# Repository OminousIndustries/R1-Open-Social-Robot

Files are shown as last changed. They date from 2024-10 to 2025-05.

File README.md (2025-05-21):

# R1 DIY Robot Kit

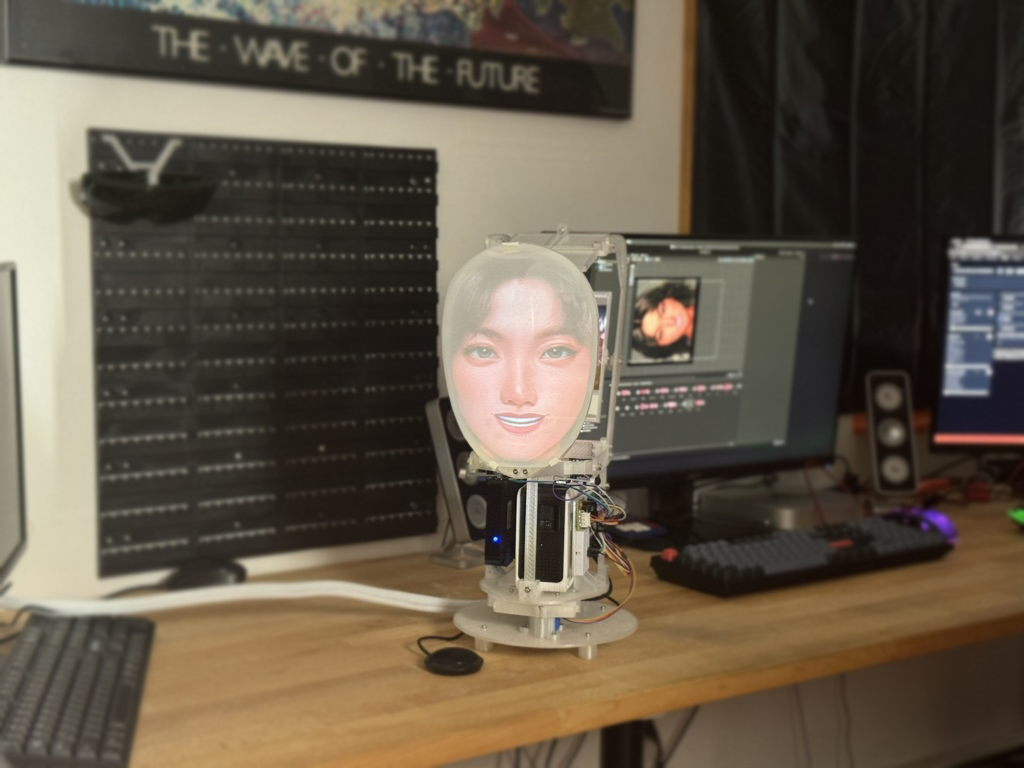
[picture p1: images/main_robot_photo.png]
Assembled R1 DIY Robot

*Assembled R1 DIY Robot with face projection, ready for interaction.*

Welcome to the **R1 DIY Kit**! These files contain every step needed to manufacture and build your very own R1 robot. This DIY kit is based on the original R1 design, with the same internal design and hardware. 

While most instructions are provided in video format, important details can also be found in the accompanying README PDFs throughout the repository. Please read the provided documentation carefully to ensure successful assembly and setup.

## Table of Contents

1. [Gather Required Parts](#gather-required-parts)
2. [3D Printing Files](#3d-printing-files)
3. [Build Instructions](#build-instructions)
4. [Software Setup](#software-setup)
   - [Pre-Setup](#pre-setup)
   - [Robot Computer Setup](#robot-computer-setup)
   - [Installing Unity](#installing-unity)
   - [Starter Mode for Mac](#starter-mode-for-mac)
   - [Starter Mode for Windows](#starter-mode-for-windows)
   - [Face Adjustment](#face-adjustment)
   - [Pausing the Robot](#pausing-the-robot)
   - [Custom Faces](#custom-faces)
   - [Arduino Setup](#arduino-setup)
   - [Advanced Mode](#advanced-mode)
5. [Unity Project Files](#unity-project-files)
6. [Connecting to a Local LLM](#connecting-to-a-local-llm)
7. [Connecting to Google Gemini API](#connecting-to-google-gemini-api)

---

## 1. Gather Required Parts

Before you begin building, print the files and gather all the necessary parts. Here is the bill of materials with links to the components you will need to purchase:

- [Parts List README (PDF)](./pre-setup/R1_Parts_List_README.pdf)

---

## 2. 3D Printing Files

The robot's frame is 3D printed. All the necessary STL files and instructions for printing are included in the following folder. Please refer to the "Printing Guide PDF" for important details about printing the pieces:

- [STL Files for 3D Printing](./build-instructions/Printing_Files)
- [Printing Guide (PDF)](./build-instructions/R1_Printing_Readme.pdf)

---

## 3. Build Instructions

Once you have printed all the parts, it's time to assemble the robot. Follow the video link and refer to the provided assembly guide for detailed instructions:

- [Assembly Instructions PDF](./build-instructions/Instruction_README.pdf)
- [Build Instruction Video](https://youtu.be/2tXyRC_KmT0)

---

## 4. Software Setup

After building the robot, the next step is setting up the software. Most of the instructions are in video format, and the following index outlines the sequence to follow for setting everything up.

### Pre-Setup

Start by setting up the required API keys. You will need both an OpenAI API Key and an Azure Key.

- [Azure Key Setup Video](https://youtu.be/wxKWgDN9a2c)
- [OpenAI Key Setup Video](https://youtu.be/aMjvTZvdCsI)

---

### Robot Computer Setup

Next, set up the robot's computer to run the required software. Follow the instructions in the video below:

- [Computer Setup Video](https://youtu.be/bzLXkPkEXfA)

---

### Installing Unity

You will need to install a specific version of Unity to configure the robot. This guide covers installation for both Mac and Windows users:

- [Unity Installation Video (Cross-platform)](https://youtu.be/6DMLwrmqWGs)

---

### Starter Mode for Mac

Mac users should follow the instructions in the video below to set up Starter Mode for the robot:

- [Starter Mode Mac Video](https://youtu.be/YG3O_CxVHSQ)

---

### Starter Mode for Windows

Alternatively, Windows users can follow this video for setting up Starter Mode:

- [Starter Mode Windows Video](https://youtu.be/5EzZFH6TbZU)

---

### Face Adjustment

Once the software is set up, you may want to adjust the robot's projected face. This video provides a comprehensive overview of how to make these adjustments. Make sure to read the accompanying PDF for important projector notes:

- [Face Adjustment Video](https://youtu.be/Ks0d70vO0KM)
- [Projector README (PDF)](./face-adjustment/Projector_README.pdf)

---

### Pausing the Robot

To learn how to pause and resume the robot while it is running, refer to the following video:

- [Pausing the Robot Video](https://youtu.be/hnXKXJgQXd8)

---

### Custom Faces

You can add custom faces to the robot. Instructions are available for both Mac and Windows users. Additionally, the face template images referenced in the instructional videos are included:

- [Custom Faces for Mac Video](https://youtu.be/4W-XHF8ed94)
- [Custom Faces for Windows Video](https://youtu.be/J4PsrUzNvfo)
- [Face Template Images](./custom-faces/Face_Template_Images)

---

### Arduino Setup

The Arduino controls the head movement of the robot. Use the following instructions to set it up, and make sure to use the provided circuit diagram and Arduino sketches:

- [Arduino Setup Video](https://youtu.be/LZN1rNx5XJ8)
- [Circuit Diagram (PNG)](./arduino-setup/Circuit_Diagram.png)
- [Simple Sketch (Arduino Script)](./arduino-setup/Simple_Sketch.ino)
- [Advanced Sketch (Arduino Script)](./arduino-setup/Advanced_Sketch.ino)

---

### Advanced Mode

For more advanced functionality, such as modifying the robot's mouth sprites and other detailed features, follow the instructions in the advanced video below:

- [Advanced Mode Video](https://youtu.be/tfWZQt3Dw8M)

---

## 5. Unity Project Files

The R1 robot has two versions of the Unity project, each with different mouth sprites. The **r1-starter-mode-f** contains female mouth sprites, while **r1-starter-mode-m** contains male mouth sprites. You can choose which one to use based on your preference:

- [Starter Mode Female Project (Unity)](./r1-starter-mode-f)
- [Starter Mode Male Project (Unity)](./r1-starter-mode-m)

---

## 6. Connecting to a Local LLM

The R1 robot can be powered by a locally hosted language model, providing real-time conversational abilities. These instructions cover setting up the robot to work with [Oobabooga's text-gen-webui](https://github.com/oobabooga/text-generation-webui) as the backend for a Local LLM.

This setup allows the robot to connect to and be powered by a locally hosted AI model of your choosing.

### Step-by-Step Instructions

1. **Setting Up the Unity Project**:
   - Navigate to the `LocalLLM` folder, which contains two scripts: `RoboLogic.cs` and `RoboListen.cs`.
   - In your Unity project, open the existing `RoboLogic.cs` and `RoboListen.cs` scripts.
   - Replace the contents of these scripts with the versions from the `LocalLLM` folder. This will configure the robot to communicate with the local LLM setup.

2. **Starting the Web UI with the Correct Flags**:
   - Launch the web UI with the `--listen` flag to allow external connections.
   - In the web UI, go to the **Session** tab and select the **OpenAI** extension. Click **Apply** and restart the session.

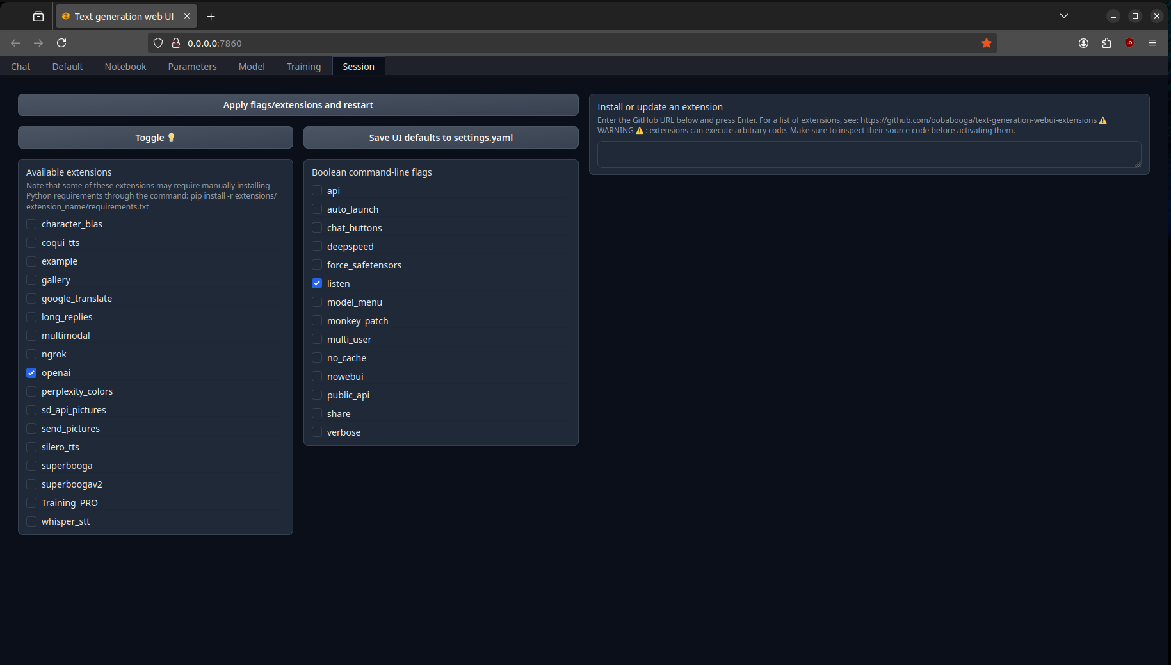
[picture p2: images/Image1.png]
Session Tab - OpenAI Extension
   

3. **Load Your Chosen Model**:
   - Load the AI model you wish to use as you normally would within the web UI.
   - Ensure that the machine running the web UI is configured to allow communication on **port 5000**, which is required for the robot to connect.

   For more detailed information on setting up the OpenAI API within the text-gen-webui, refer to [this guide](https://github.com/oobabooga/text-generation-webui/wiki/12-%E2%80%90-OpenAI-API).

4. **Configuring Unity for Local LLM Connection**:
   - In Unity’s **Inspector** pane, enter the name of the character you wish to communicate with in the web UI, as well as the endpoint URL for the web UI machine.

   Local LLM Connection Settings in Unity Inspector

   - To find the character name in the web UI, go to **Parameters > Chat > Character**.

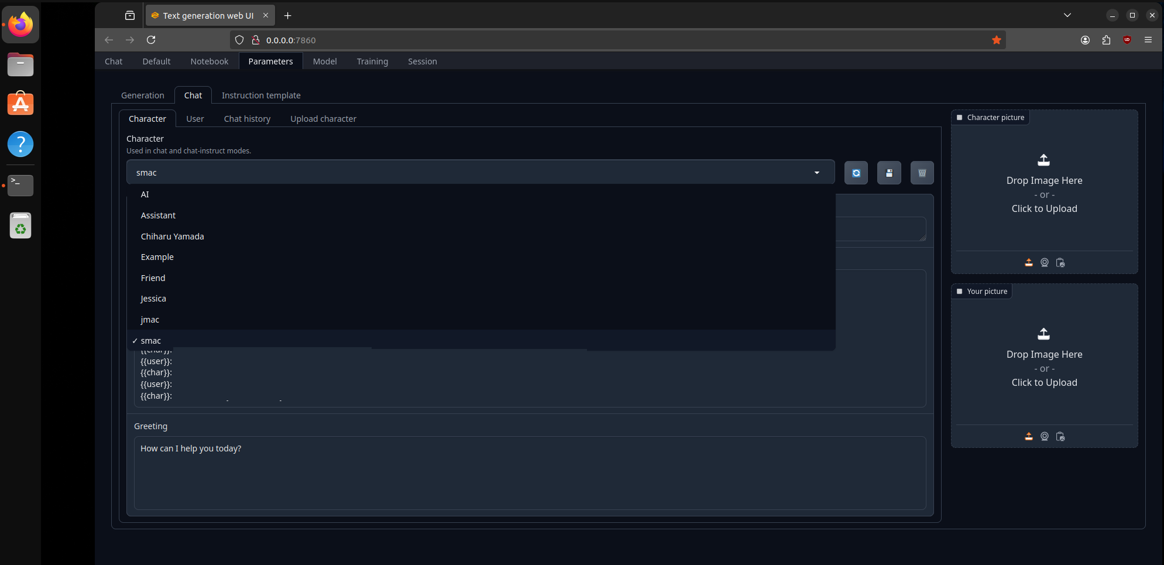
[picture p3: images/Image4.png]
Character Selection in Web UI
   

5. **Testing the Connection**:
   - If everything is configured correctly, you should see the LLM processing requests from the robot in the terminal where the web UI is running.

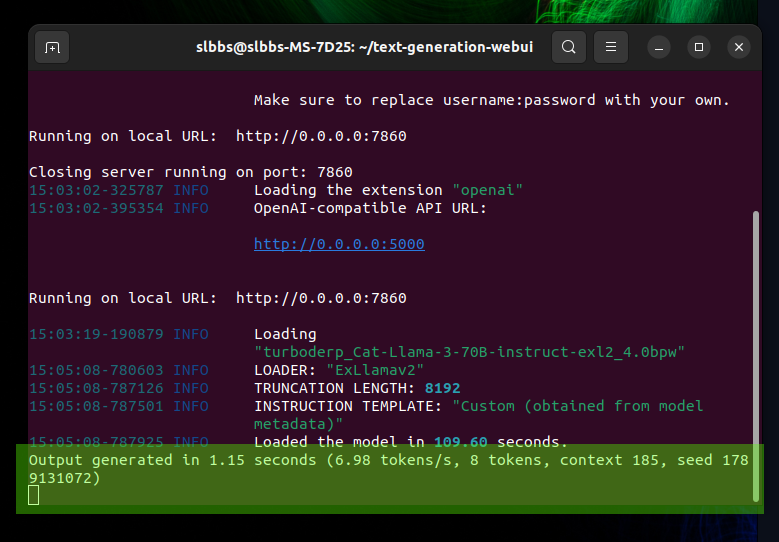
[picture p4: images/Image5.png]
Terminal Output on LLM Machine
   

---

## 7. Connecting to Google Gemini API

The R1 robot can also be configured to use Google's Gemini API for its conversational abilities, as an alternative to a local LLM or other services. This setup uses the `RoboLogic.cs` script which has been adapted for the Gemini API.

### Prerequisites:

*   **Google Cloud Project:** You need a Google Cloud Project set up.
*   **Gemini API Enabled:** Ensure the "Generative Language API" (or "Vertex AI API" if accessing Gemini through Vertex) is enabled for your project.
*   **API Key:** You must have an API key associated with your project that is authorized to use the Gemini API.

### Step-by-Step Instructions:

1.  **Obtain your Google API Key:**
    *   Go to the [Google Cloud Console](https://console.cloud.google.com/).
    *   Navigate to your project.
    *   Go to "APIs & Services" > "Credentials".
    *   Create a new API key if you don't have one, or use an existing key. Ensure it's properly restricted for security, but allows access to the Generative Language API.
    *   **Important:** Keep this API key secure. Do not share it publicly or commit it directly into version control if you are managing your project on a public repository.

2.  **Configure Unity Project:**
    *   Open your R1 Unity project (e.g., `r1-starter-mode-f` or `r1-starter-mode-m`).
    *   Locate the GameObject that has the `RoboLogic.cs` script attached to it (this is typically the main robot controller object).
    *   In the Unity Inspector window for this GameObject, you will find the following fields under the "Robo Logic" component:
        *   **Gemini Api Key:** Paste your Google API Key here.
        *   **Gemini Model Name:** Enter the specific Gemini model you wish to use (e.g., `gemini-1.5-flash-latest`, `gemini-pro`, `gemini-1.0-pro`). The default is often `gemini-1.5-flash-latest`. You can find available model names in the [Google AI documentation](https://ai.google.dev/models/gemini).

    Gemini API Connection Settings in Unity Inspector 
    *(Note: You will need to add an illustrative image named `Gemini_Inspector_Setup.png` to the `images/` directory later if you want this image to show. For now, the markdown link is a placeholder.)*

3.  **Ensure Correct Scripts:**
    *   Make sure the `LocalLLM/RoboLogic.cs` script in your Unity project is the version that has been modified for Gemini API access. If you downloaded the project after these changes, it should be correct. If you are modifying an older version, ensure you've updated the script.

4.  **Testing the Connection:**
    *   Run the Unity scene.
    *   When the robot attempts to get a response (e.g., after speech-to-text processing via `RoboListen`), it will now call the Google Gemini API.
    *   Check the Unity Console for any log messages from `RoboLogic.cs`. Successful calls will log the received response, while errors will detail issues with the API key, model name, endpoint, or network connectivity.

### Important Considerations:

*   **API Costs:** Using the Google Gemini API may incur costs based on your usage. Familiarize yourself with the [Gemini API pricing](https://ai.google.dev/pricing).
*   **Rate Limits:** Be aware of any rate limits imposed by the API to avoid service interruptions.
*   **Security:** Handle your API key with care. For more advanced or production scenarios, consider more secure ways to manage API keys rather than pasting them directly into the Inspector, such as using environment variables or a secure configuration service (though this is beyond the scope of the current basic setup).

---

If you have any questions, feel free to reach out to me. Enjoy building your R1 robot, and remember to follow all safety guidelines when working with tools and equipment!

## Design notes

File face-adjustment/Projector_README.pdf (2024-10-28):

## R1 ROBOT PROJECTOR README

Projector Setup:
The R1 has been designed around the Yoton Y3 projector, as it provides a large amount of light and a high quality image. The projector includes an internal speaker which outputs a suitable volume level for a home setting. If you would like, a 3.5mm aux cable plugged into the bottom headphone jack on the projector will allow you to plug into an external speaker system to output a louder volume.
The Yoton Y3 Projector has a keystone and focus knob which must be adjusted until the screen is clearly displayed on the Face Sheet. The Projector’s instruction manual will guide you on how to do this.

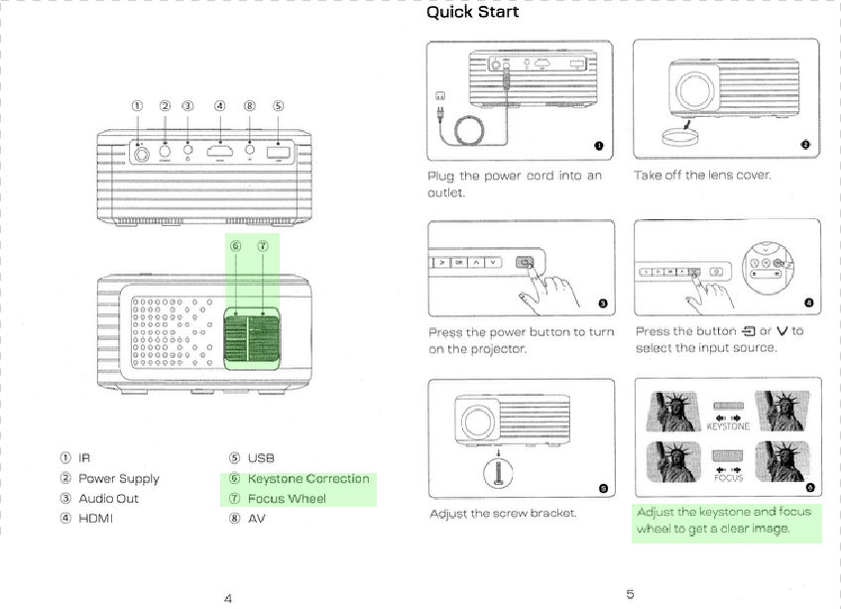
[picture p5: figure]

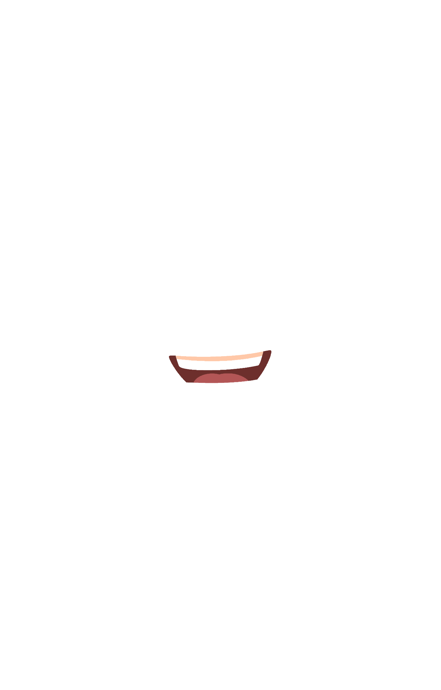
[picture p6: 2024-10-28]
r1-starter-mode-m/Assets/1Robot_Starter_Mode/Sprites/Mouth_Sprites/a,-e,-i.png

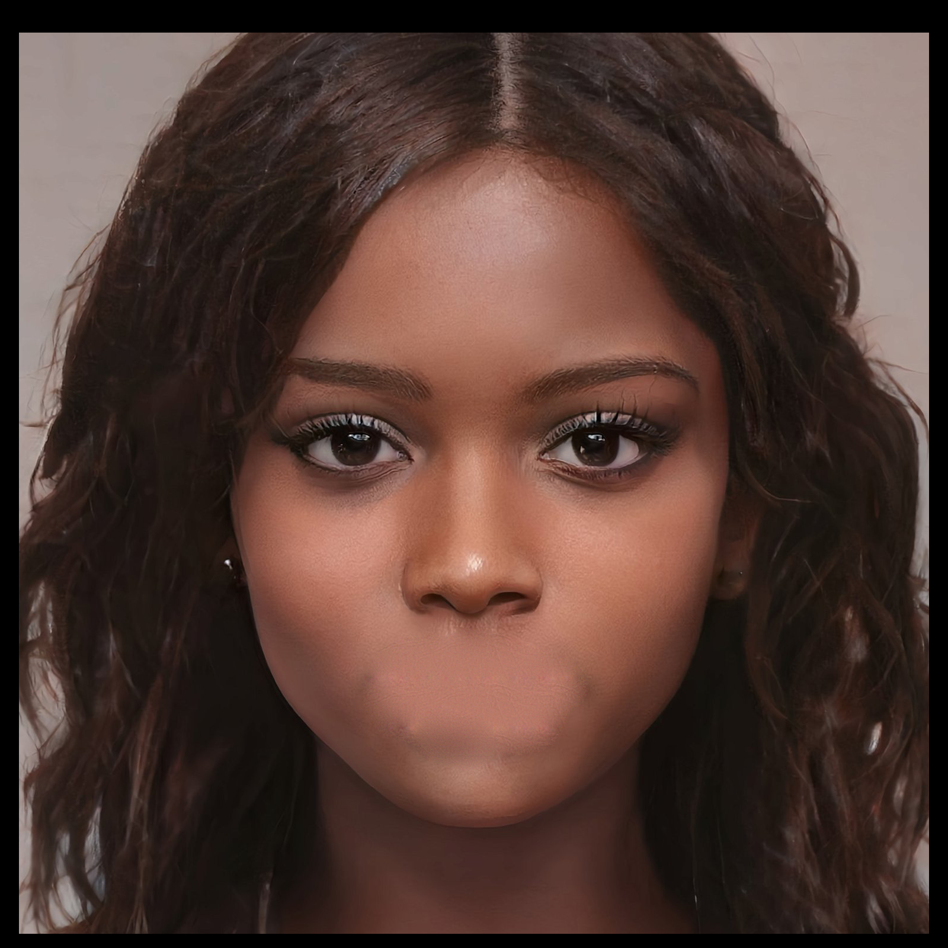
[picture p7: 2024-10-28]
r1-starter-mode-f/Assets/1Robot_Starter_Mode/Sprites/Faces/Face2.png

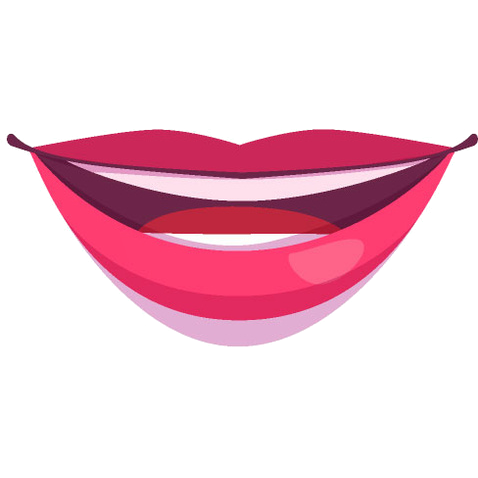
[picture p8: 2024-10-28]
r1-starter-mode-f/Assets/1Robot_Starter_Mode/Sprites/Mouth_Sprites/aei.png

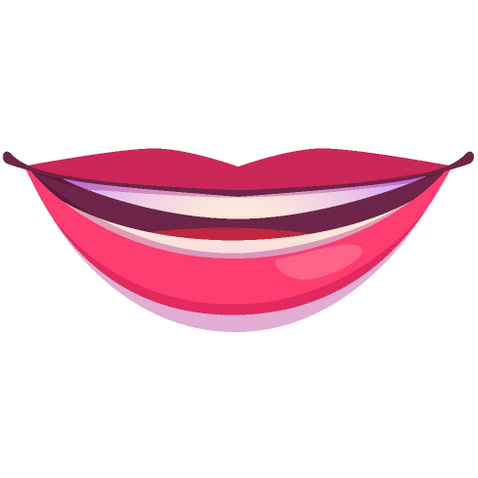
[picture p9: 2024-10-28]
r1-starter-mode-f/Assets/1Robot_Starter_Mode/Sprites/Mouth_Sprites/cdgh.png

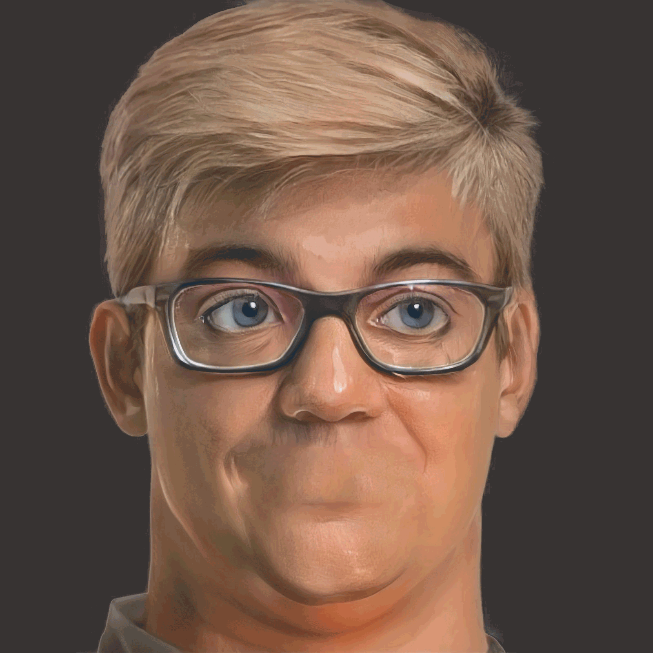
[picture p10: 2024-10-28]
r1-starter-mode-m/Assets/1Robot_Starter_Mode/Sprites/Faces/man3x.png

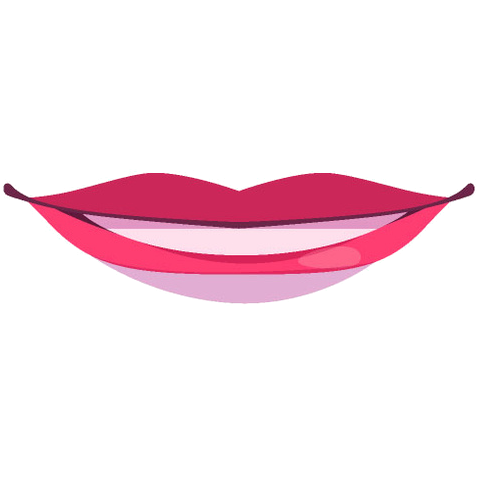
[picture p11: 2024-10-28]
r1-starter-mode-f/Assets/1Robot_Starter_Mode/Sprites/Mouth_Sprites/fv.png

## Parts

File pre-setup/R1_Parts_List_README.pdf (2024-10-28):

R1BOM.md | 2024-10-28

1 / 2

# R1 Robot Bill Of Materials

## Electronic Components

Yoton Y3 Mini Projector: Link (https://amzn.to/40mGHHc)
The Robot is designed to use this specific projector. Other Mini Projectors may work, but this cannot be guaranteed.

T95 Super Android TV Box: Link (https://amzn.to/48n9oWm)
This is the Robotʼs computer. Alternative Android TV boxes, such as the T95 Mini, may work, but this cannot be guaranteed.

Genuine Arduino Uno R3: Link (https://amzn.to/40lqDoL)

Elegoo Arduino Uno R3: Link (https://amzn.to/4e5dfs8)
Generic Uno R3 models, like the Elegoo model, can also work if you are familiar with Arduino.

28BYJ-48 Stepper Motor & ULN2003 Driver Board: Link (https://amzn.to/3NOcMzP)
The robot only needs one of each, but they are sometimes cheaper and more readily available to purchase as a package.

Mini Breadboard 170 Point: Link (https://amzn.to/3NH0glL)
This is the recommended size breadboard to use with the R1.

LM393 3-Pin Arduino Sound Level Sensor: Link (https://amzn.to/48kJJO5)
(Two Sensors Required) It is advised to use the 3-Pin LM393-based sound level sensors. If you are familiar with Arduino, you may also adapt the 4-Pin sensors.

Arduino Jumper Wires: Link (https://amzn.to/4fj8cWf)
The Robot needs 12 M-F and 2 M-M 20CM Jumper wires.

Generic USB Microphone: Link (https://amzn.to/4ebU9Ru)
Any universal microphone should work with the Robotʼs computer, but this cannot be guaranteed.

1 foot HDMI Cable: Link (https://amzn.to/3C0lubH)
A 1-foot HDMI cable is easy to neatly tuck behind the robot.

Right-Angle Male to Female HDMI Adaptor: Link (https://amzn.to/4fl01Zp)
Either the 90 or 270-degree adaptors will work as the cable will reach on either side.

USB A to USB A Cable: Link (https://amzn.to/3YG3EUr)
This is to transfer the software from your computer to the Robotʼs computer. If you plan to use ADB to transfer files instead, this cable is not necessary.

## Hardware

3mm thick 6”x4” Acrylic Mirror: Link (https://amzn.to/3Ah2g12)
(Two Mirrors Required) For the DIY Kit R1, both mirrors are the same size, as opposed to the larger rear mirror displayed in the instructions. Any 3mm thick 6” by 4” mirror should work. Some multi-

R1BOM.md | 2024-10-28

2 / 2

pack mirrors on Amazon may appear to be the right size, but are really 3.9" by 5.9" and will not fit in the robot. Using these would require modifying the robot's mirror holders.

10 mil Mylar Sheet 12 x 12 inch Milky Translucent PET: Link (https://amzn.to/3C0lFDT)
This material allows the face to be projected on the robot. Other materials may work, but 10mil milky translucent PET has worked well in prototyping.

Hex Socket Head M4 Screw and Nut Set: Link (https://amzn.to/4fizBHM)
Most of the Robotʼs assembly requires M4 sized hardware.

Hex Socket Head M2, M3, M4 Screw and Nut Set: Link (https://amzn.to/4hpga1E)
Some M2 and M3 hardware is also necessary, and this also supplies extra M4 hardware if needed.

4mm Nylon Spacer for Sound Level Sensor: Link (https://amzn.to/4hpfZ6u)
This is not required as the sound level sensors can mount directly to the front crossmember, but these spacers allow the sensors to sit at a better angle.

Two 1kg Rolls of 3D Printer Filament of Your Choosing: Link (https://amzn.to/4hpikyk)
There is no specific recommendation for filament type. Choose any color and material you prefer; two 1kg rolls should be plenty. Esun PLA Plus has been reliable in prototyping.

As an affiliate, I may earn a commission from qualifying purchases at no extra cost to you.

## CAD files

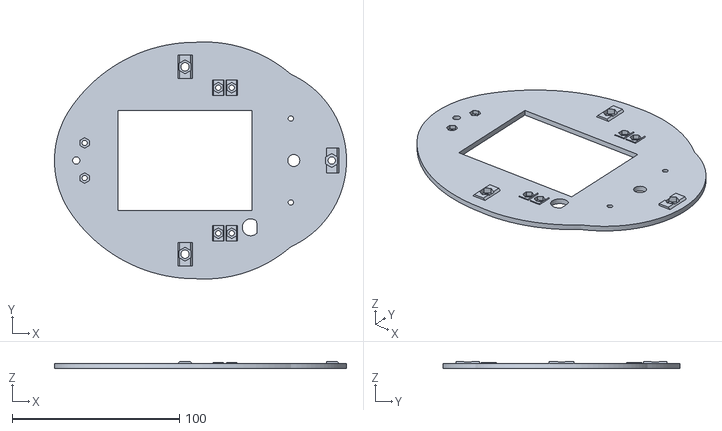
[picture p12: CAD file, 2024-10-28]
build-instructions/Printing_Files/Base/Robo_Base.stl
174.5 x 141.7 x 4.15

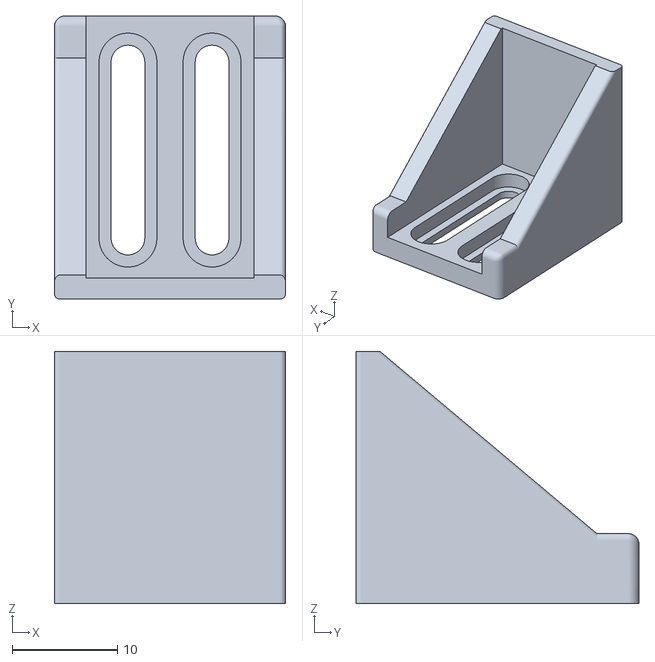
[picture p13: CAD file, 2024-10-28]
build-instructions/Printing_Files/Clamps/Side_Projector_Clamp.stl
22.0 x 26.9 x 24.0

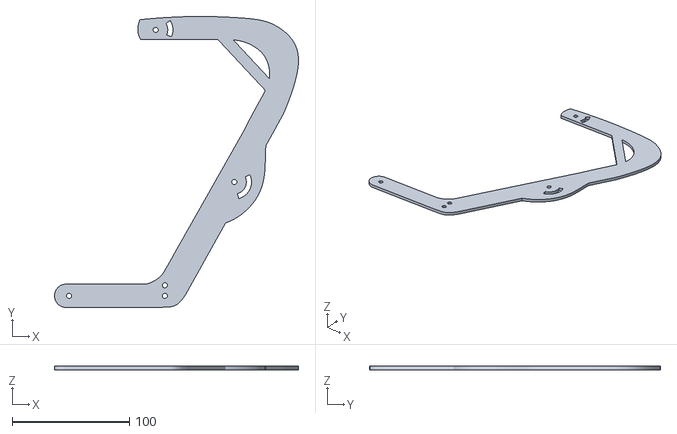
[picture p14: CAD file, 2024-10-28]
build-instructions/Printing_Files/HeadFrame/Head_Frame.stl
208.4 x 248.5 x 3.00

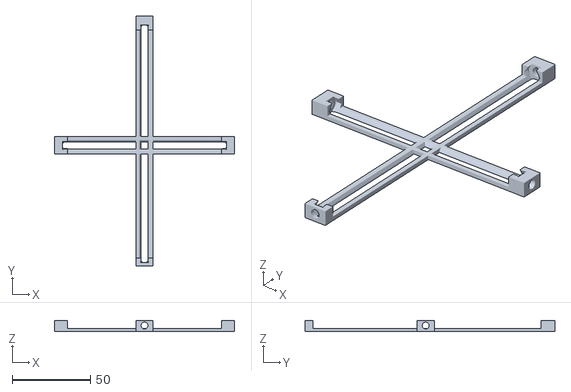
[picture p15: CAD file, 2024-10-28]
build-instructions/Printing_Files/Mirrors/Top_Mirror_Bridge.stl
115.0 x 159.4 x 6.96

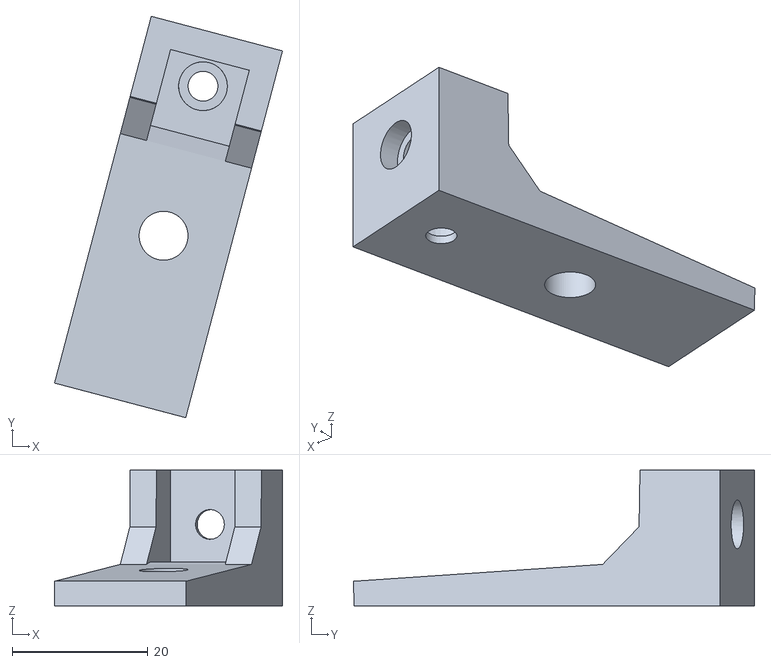
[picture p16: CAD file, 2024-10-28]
build-instructions/Printing_Files/Mounts/Front_Post_Mount.stl
33.6 x 59.1 x 20.0

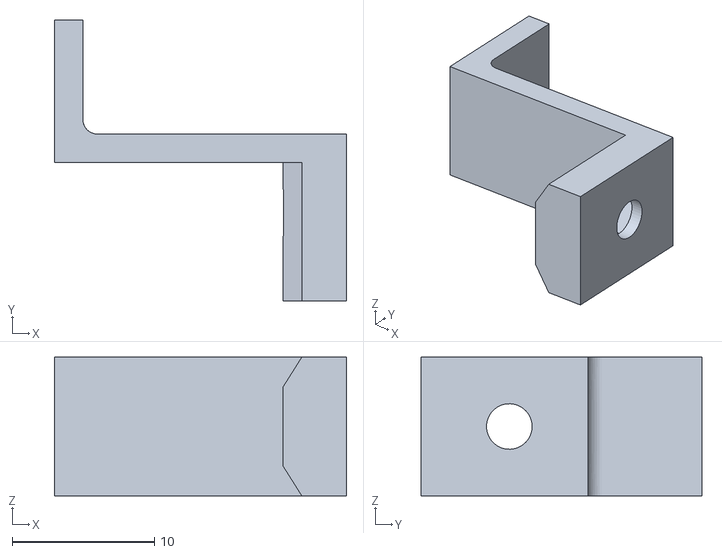
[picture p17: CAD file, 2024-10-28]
build-instructions/Printing_Files/Posts/Top_Computer_Bracket.stl
20.5 x 19.7 x 9.75

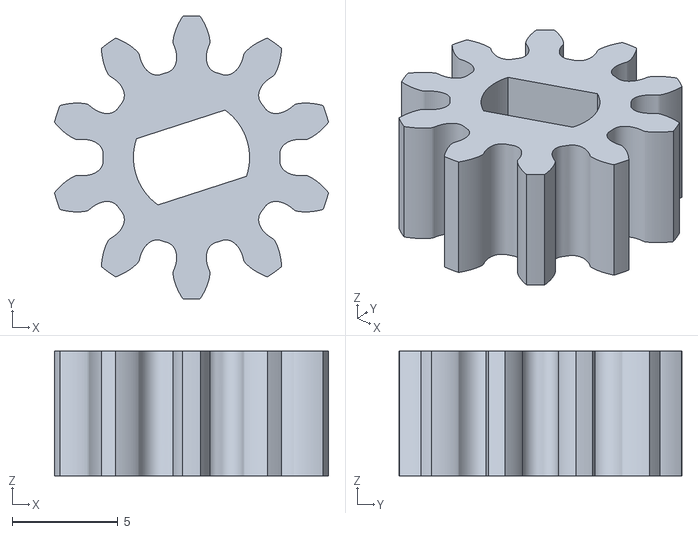
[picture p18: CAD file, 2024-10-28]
build-instructions/Printing_Files/Base/Gear_Updated.stl
13.0 x 13.4 x 5.90

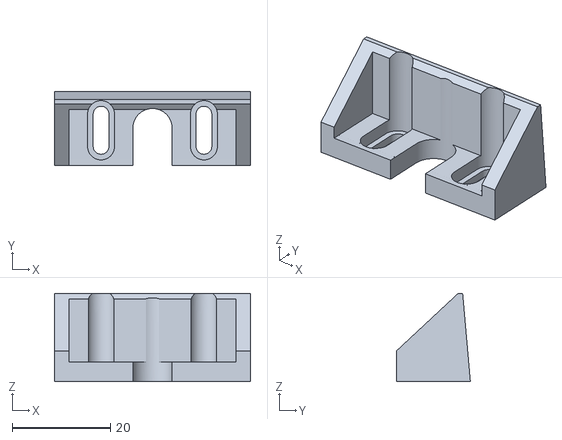
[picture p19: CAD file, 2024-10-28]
build-instructions/Printing_Files/Clamps/Rear_Projector_Clamp.stl
40.0 x 15.1 x 18.0

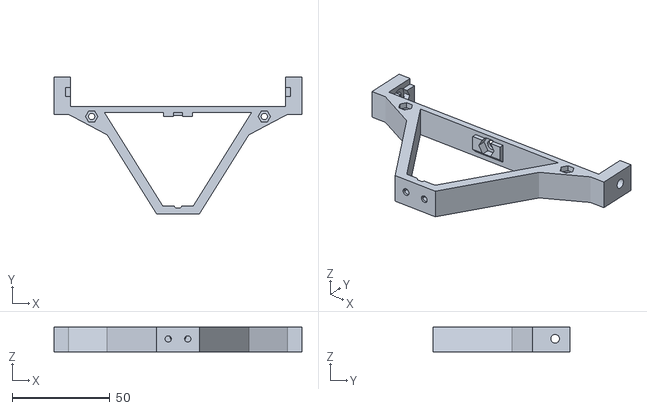
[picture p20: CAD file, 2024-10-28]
build-instructions/Printing_Files/HeadFrame/Front_Crossmember.stl
127.0 x 70.0 x 12.8

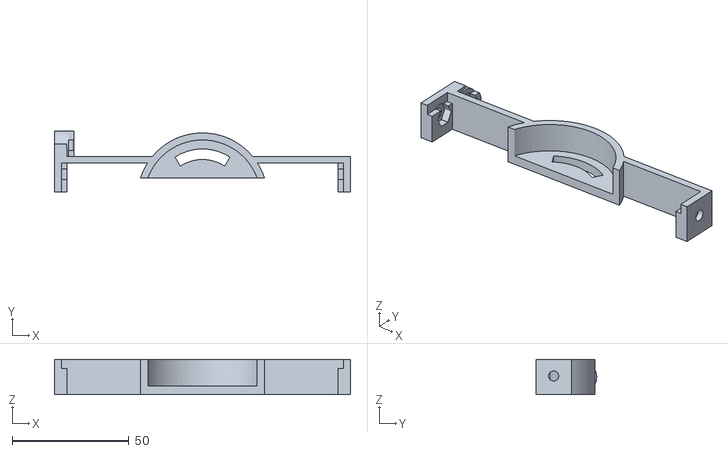
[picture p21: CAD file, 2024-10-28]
build-instructions/Printing_Files/Mirrors/Rear_Mirror_Support.stl
127.0 x 26.0 x 15.1

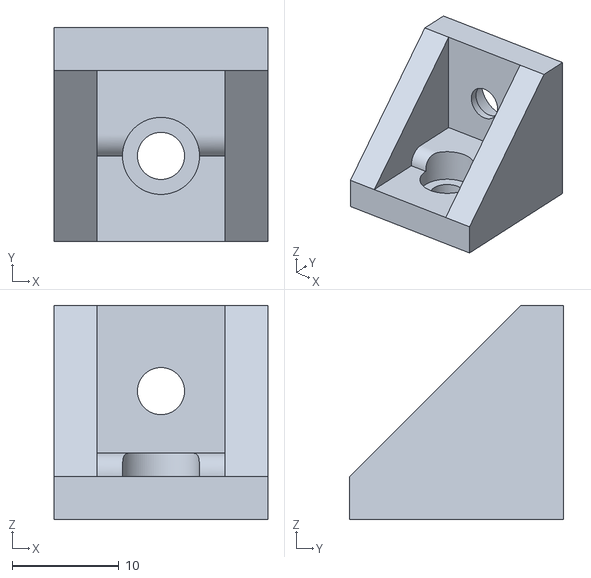
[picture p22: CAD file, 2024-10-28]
build-instructions/Printing_Files/Mounts/Side_Post_Mount.stl
20.0 x 20.0 x 20.0

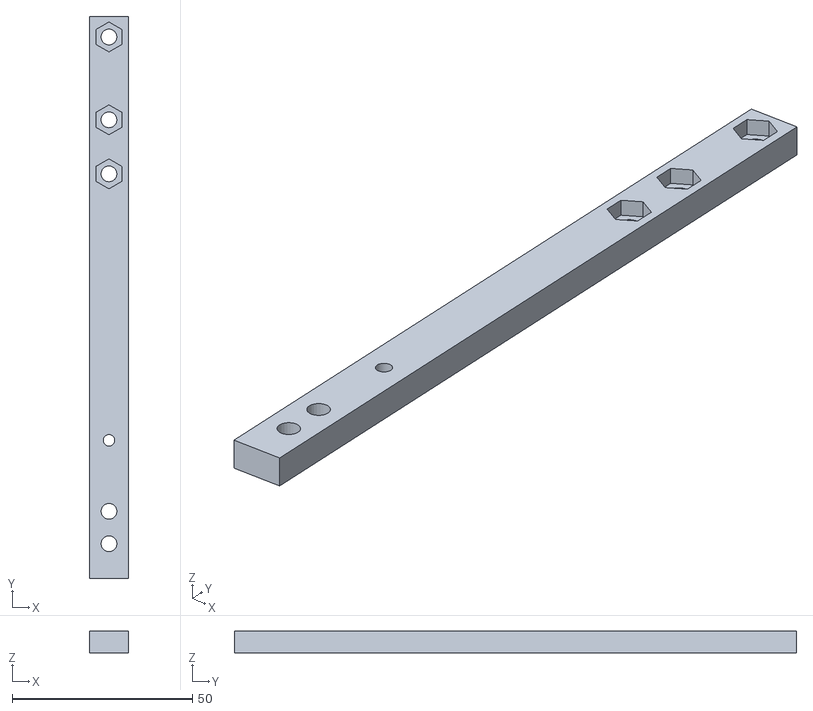
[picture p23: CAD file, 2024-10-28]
build-instructions/Printing_Files/Posts/Computer_Side_Post.stl
10.8 x 156.0 x 6.00

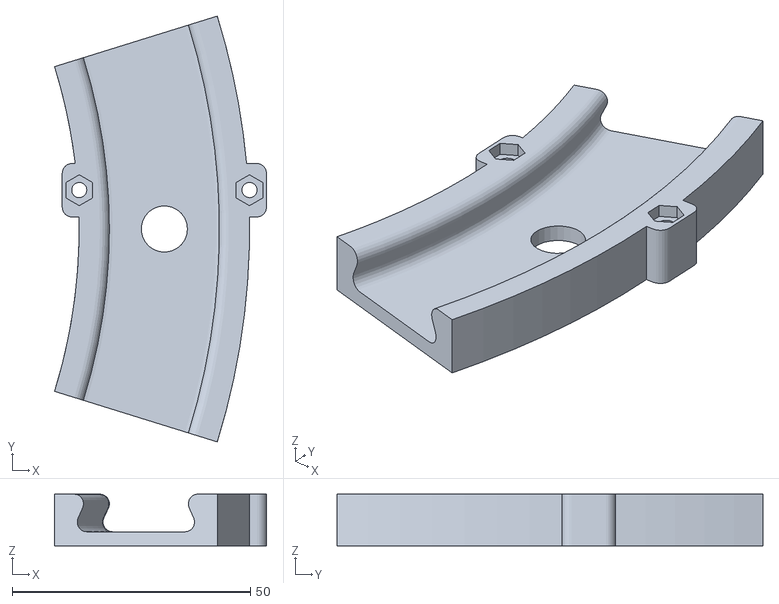
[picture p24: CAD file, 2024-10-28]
build-instructions/Printing_Files/Base/Rail_Slider.stl
44.5 x 89.3 x 10.9

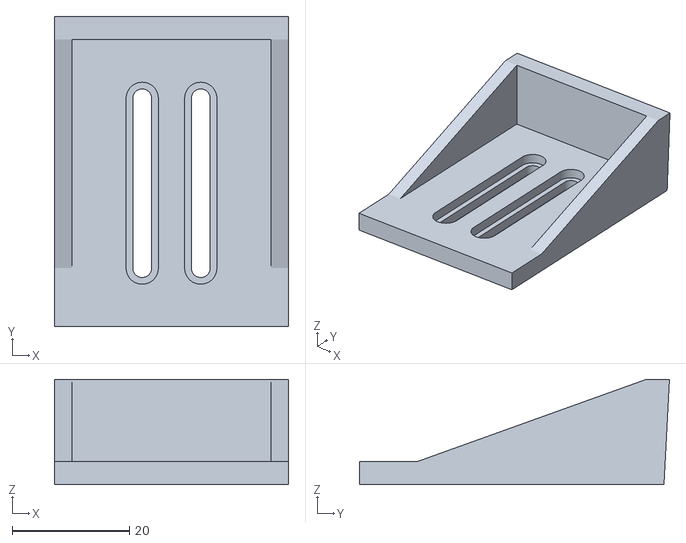
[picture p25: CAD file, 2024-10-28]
build-instructions/Printing_Files/Clamps/Top_Projector_Clamp.stl
40.0 x 52.9 x 18.0

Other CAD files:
build-instructions/Printing_Files/HeadFrame/Face_Bezel.stl
build-instructions/Printing_Files/Mirrors/Rear_Mirror_Bridge.stl
build-instructions/Printing_Files/Posts/Arduino_Mount.stl
build-instructions/Printing_Files/Base/Motor_Mount.stl
build-instructions/Printing_Files/Base/Base_Plate.stl
build-instructions/Printing_Files/Base/Gear_Rail.stl
build-instructions/Printing_Files/Base/Rear_Base_Mount.stl
build-instructions/Printing_Files/Base/Robo_Foot.stl
build-instructions/Printing_Files/HeadFrame/Rear_Crossmember.stl
build-instructions/Printing_Files/Mirrors/Rear_Mirror_Bezel.stl
build-instructions/Printing_Files/Mirrors/Top_Mirror_Bezel.stl
build-instructions/Printing_Files/Posts/Arduino_Side_Post.stl
build-instructions/Printing_Files/Posts/Computer_Mount.stl
build-instructions/Printing_Files/Posts/Front_Post.stl

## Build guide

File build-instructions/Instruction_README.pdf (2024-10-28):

## R1 ROBOT INSTRUCTION README

Because this kit is designed to be easily assembled at home, the two piece external shell from the old R1 has been replaced with a simpler face sheet that can be easily built. Due to this change, some of the instructions in the R1 build video will be slightly different to what you will be building here. Highlighted below are the changes made to be aware of when watching the instruction build video:
In Step 22, The M4 Lock Nut may have a different colored gasket than the blue that is mentioned in the video.
In Step 33, The Computer Side Post no longer requires the two parallel M4 nuts that go in the protruded areas.

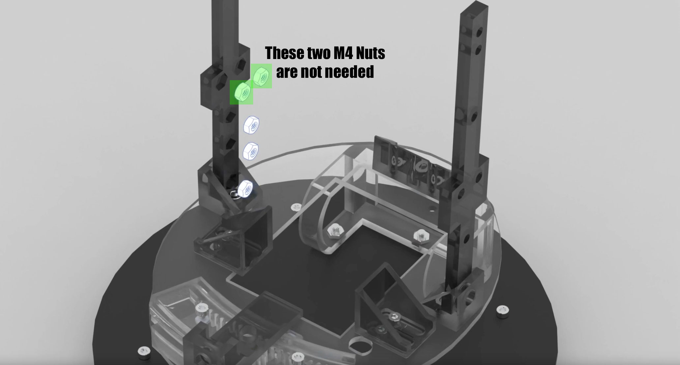
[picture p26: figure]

In Step 34, the Arduino Side Post shows a post with a side protrusion for two M4 nuts. The updated post does not have these protrusions and does not need the nuts placed there. (See Image Below)

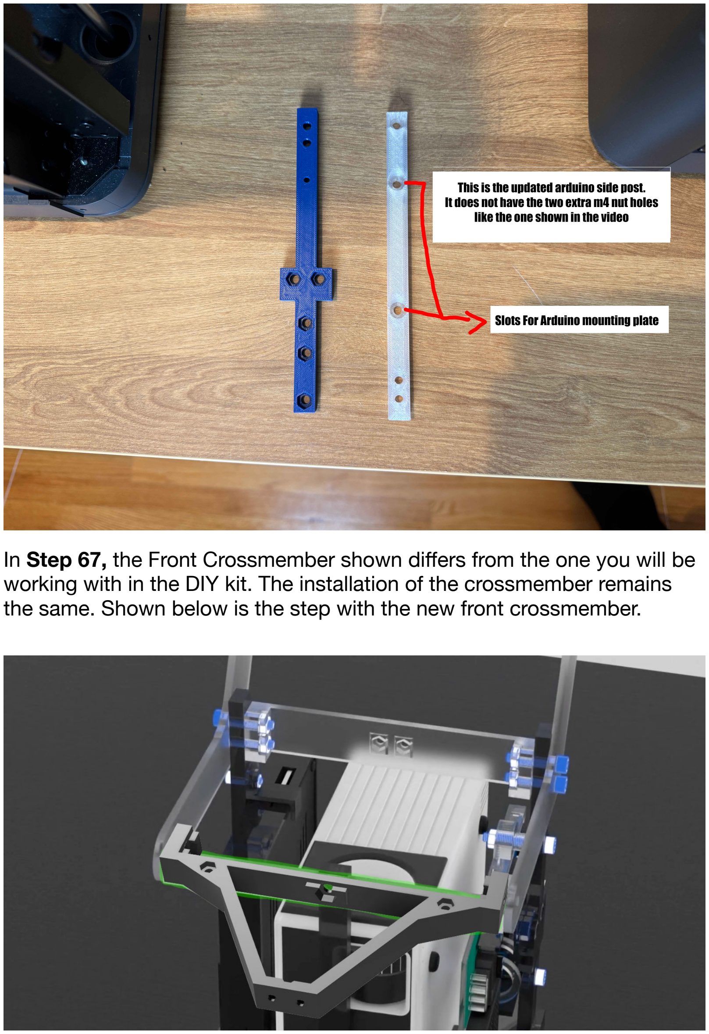
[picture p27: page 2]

In Step 67, the Front Crossmember shown differs from the one you will be working with in the DIY kit. The installation of the crossmember remains the same. Shown below is the step with the new front crossmember.

The two mirrors used in the Robot are the same size in the DIY kit. Due to this, the mention of the larger rear mirror beginning just before Step 82, can be ignored as both mirrors are the same size.
The Build Instruction video skips from Step 105 to Step 123, as the skipped steps are related to the old R1 and not required for the DIY kit.

**The Mounting of the Face Bezel and PET sheet are not shown in the instruction video. See below for these instructions:

Step 1: Place the Face Bezel over the PET sheet and use it as a stencil, cutting out the PET into the shape and size of the Face Bezel.

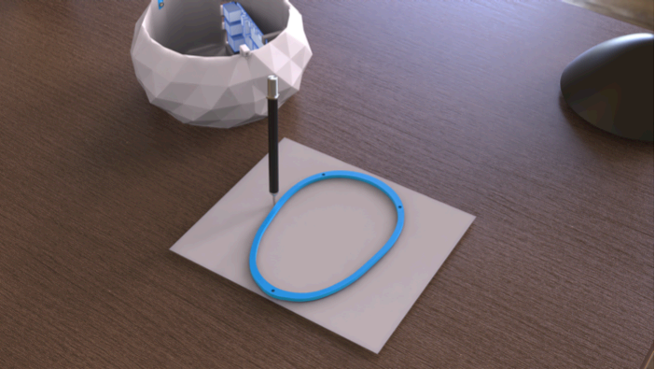
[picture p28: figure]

Step 2: With the PET sheet cut to the correct size, it will look like the image below.

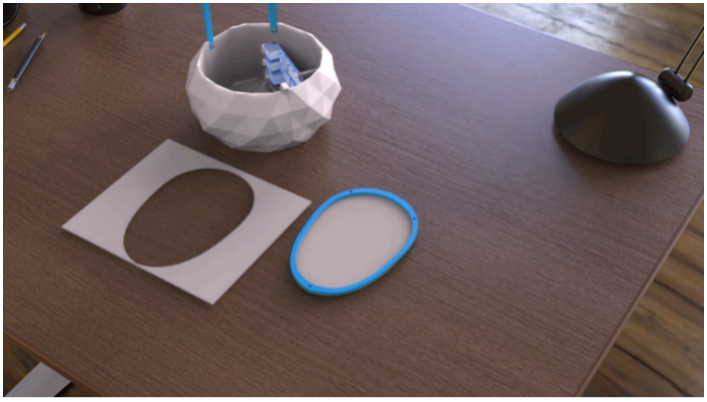
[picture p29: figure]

Step 3: The new Front Crossmember mounts the same way as the instructional video demonstrates. The difference is the two M3 nuts that must be inserted into the two recessed nut holes in the back side of the Front Crossmember, highlighted red in the below image. (See Image Below)

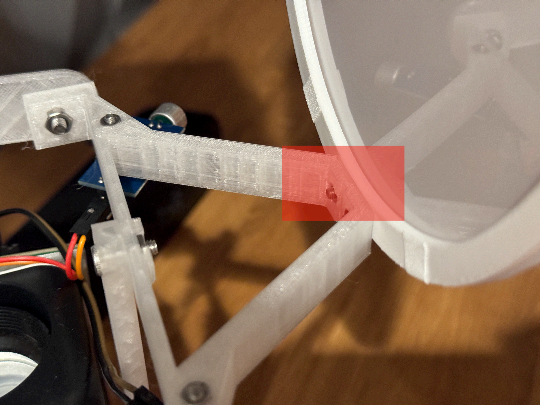
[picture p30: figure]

Step 4: With the Front Crossmember installed, use two M3x10 screws to install the Face Bezel on to the front of the crossmember, screwing it into the two M3 nuts opposing it. Using tape or any sort of adhesive, you can now freely mount the cut PET sheet on to the Face Bezel. (See Image Below)

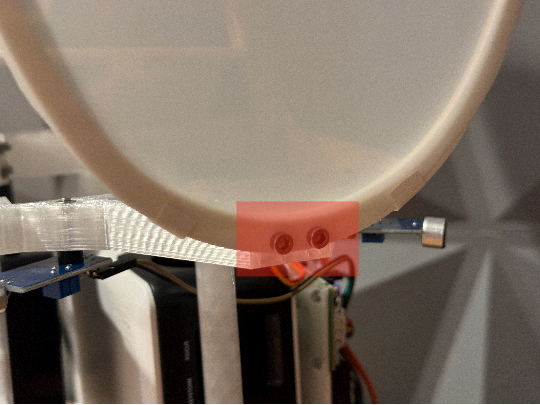
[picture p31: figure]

This concludes the instructional changes for building the DIY kit. If you have any questions, please feel free to reach out to me at: hello@stemlabkit.com

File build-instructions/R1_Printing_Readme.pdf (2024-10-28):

R1_Printing_Readme.md | 2024-10-28

1 / 2

# R1_Printing_Readme

## R1 Robot 3D Printing README

The R1 robot consists of 33 individual 3D printed parts. Each part has been specifically designed to print without the need for supports. There are no special requirements for printing; standard settings with a 0.2mm layer height and 20% infill will be sufficient for all printed components. Additionally, all .stl files are pre-oriented for optimal printing.

Minimum Printer Size Required: 256mm x 256mm x 256mm

The parts are organized into six folders. Below is a checklist of each folder and its associated parts:

Base

Base_Plate

Gear_Rail - (For better movement, a smaller layer height is recommended)
Motor_Mount

Rail_Slider - (For better movement, a smaller layer height is recommended)
Rear_Base_Mount
Robo_Base
Robo_Foot - (Print four of these)

Ten_Tooth_Gear - (For improved gear function, use a fine setting and small layer height)

Clamps

Rear_Projector_Clamp
Side_Projector_Clamp - (Print two of these) Top_Projector_Clamp

Head Frame

Face_Bezel - (Higher infill recommended for structural integrity)
Front_Crossmember

Head_Frame - (Print two of these; higher infill recommended for strength)
Rear_Crossmember

Mirrors

Rear_Mirror_Bezel
Rear_Mirror_Bridge
Rear_Mirror_Support
Top_Mirror_Bezel
Top_Mirror_Bridge

Mounts

Front_Post_Mount

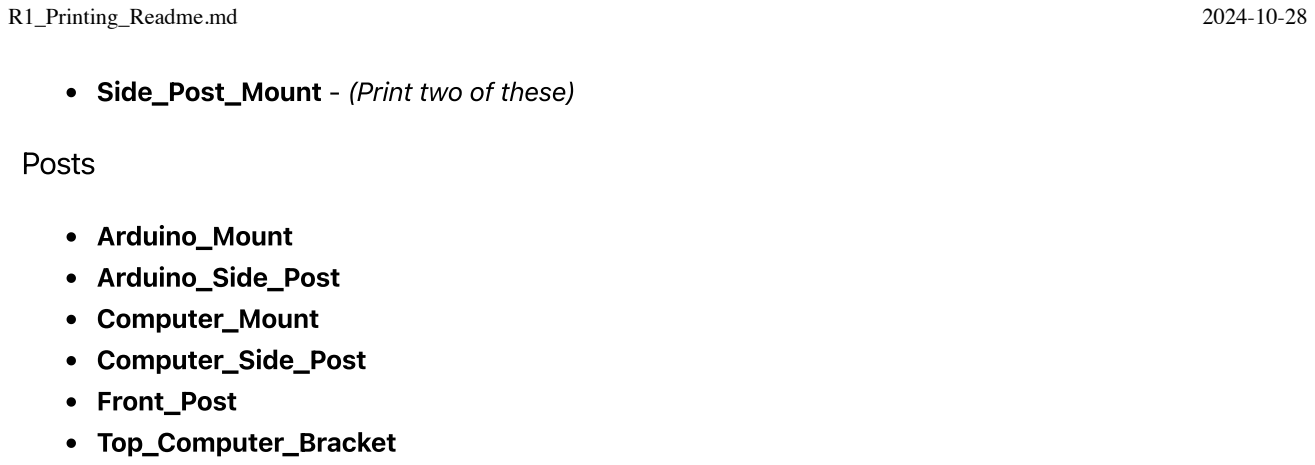
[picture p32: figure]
R1_Printing_Readme.md; Side_Post_Mount - (Print two of these); Posts; Arduino_Mount Arduino_Side_Post Computer_Mount Computer_Side_Post Front_Post Top_Computer_Bracket

2 / 2

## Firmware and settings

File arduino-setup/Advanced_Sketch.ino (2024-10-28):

//Include the Arduino Stepper Library
#include <Stepper.h>

// Define sound level sensor pins
const int right_sound = 2;  // Assuming the right sensor's OUT is connected to pin 2
const int left_sound = 3;   // Assuming the left sensor's OUT is connected to pin 3

// Define Constants 

// Number of steps per internal motor revolution
const float STEPS_PER_REV = 32;

// Amount of Gear Reduction
const float GEAR_RED = 64;

// Number of steps per geared output rotation
const float STEPS_PER_OUT_REV = STEPS_PER_REV * GEAR_RED;

// Define Variables
// Number of Steps Required
int StepsRequired;

// Create Instance of Stepper Class
// Specify Pins used for motor coils
// The pins used are 8,9,10,11
// Connected to ULN2003 Motor Driver In1, In2, In3, In4
// Pins entered in sequence 1-3-2-4 for proper step sequencing
Stepper steppermotor(STEPS_PER_REV, 8, 10, 9, 11);

void setup() {
  // Set up sound sensor input pins
  pinMode(right_sound, INPUT);
  pinMode(left_sound, INPUT);
  // Initialize Serial for debugging (optional)
  Serial.begin(9600);
}

void loop() {
  bool right_detected = (digitalRead(right_sound) == LOW); // True if sound detected on right
  bool left_detected = (digitalRead(left_sound) == LOW);   // True if sound detected on left

// CW (Clockwise) turns the head to the right
// CCW (Counter-Clockwise) turns the head to the left


  // Check if only the right_sound sensor detects sound
  if (right_detected && !left_detected) {
    // Rotate CW 1/2 turn
    StepsRequired = STEPS_PER_OUT_REV / 1;
    steppermotor.setSpeed(700);
    steppermotor.step(StepsRequired);
    delay(5000); // Wait for 5 Seconds until next instruction

    // Rotate CCW 1/2 turn to return to original position
    StepsRequired = -STEPS_PER_OUT_REV / 1;
    steppermotor.setSpeed(700);
    steppermotor.step(StepsRequired);
    delay(1000); // Wait for 1 Second before next measurement
  }
  // Check if only the left_sound sensor detects sound
  else if (left_detected && !right_detected) {
    // Rotate CCW 1/2 turn
    StepsRequired = -STEPS_PER_OUT_REV / 1;
    steppermotor.setSpeed(700);
    steppermotor.step(StepsRequired);
    delay(5000); // Wait for 5 Seconds until next instruction

    // Rotate CW 1/2 turn to return to original position
    StepsRequired = STEPS_PER_OUT_REV / 1;
    steppermotor.setSpeed(700);
    steppermotor.step(StepsRequired);
    delay(1000); // Wait for 1 Second before next measurement
  }
  // If both sensors detect sound or neither detects sound, do nothing
  else {
    delay(100);
  }
}

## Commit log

2024-10-28 Initial commit with project structure and files
    [Arduino_Mount.stl, Arduino_Side_Post.stl, Base_Plate.stl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]
2024-10-28 Configure Git LFS to track large files
2024-10-28 Convert directory names to lowercase with hyphens
    [Arduino_Mount.stl, Arduino_Side_Post.stl, Base_Plate.stl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]
2024-10-28 Fix case sensitivity in parts list readme filename
